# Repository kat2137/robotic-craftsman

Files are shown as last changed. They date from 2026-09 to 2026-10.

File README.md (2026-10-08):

# The Robotic Craftsman (Hania)

<p>
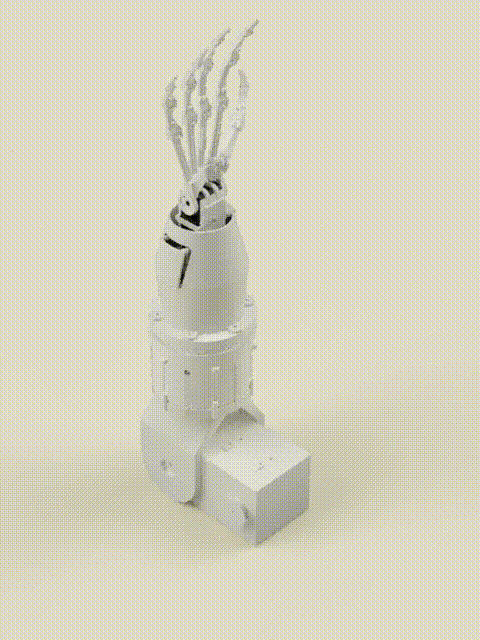
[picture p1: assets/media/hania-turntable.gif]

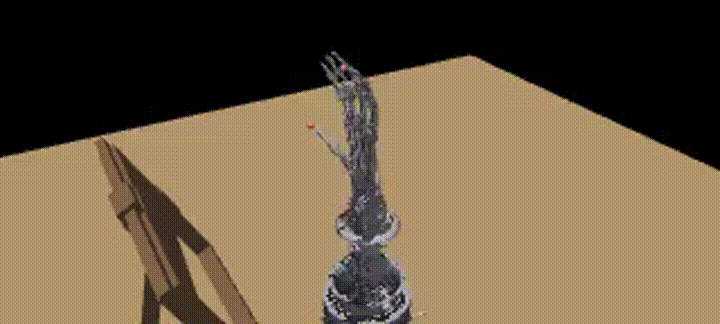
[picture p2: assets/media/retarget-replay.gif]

</p>

A robotic arm and tendon-driven hand built to reproduce hand-sewing on flimsy fabric. I filmed hand-sewing demonstrations, extracted 3D hand pose with WiLoR, and retargeted it onto my robot in MuJoCo, then onto the real arm. Arm, hand, electronics and code are my own design.

Project page: https://kat2137.github.io/dlugosz-site/

## Challenge fit
- **Own data.** All footage was collected by me: I filmed myself and other sewers on a Canon camera on a small tripod (fixed viewpoint, right hand sewing through fabric). The sample clip used below is `handsewing_01`.
- **Challenging embodiment.** Human hand → 3-DoF servo arm with a five-finger, tendon-driven hand. Task: holding and pushing a needle through deformable fabric.
- **Sim.** Retargeted trajectories replayed in MuJoCo on the robot's own model (`model/palm_with_frame.xml`, meshes exported from my Fusion 360 CAD), including a free-floating needle held between the pads.

<p>
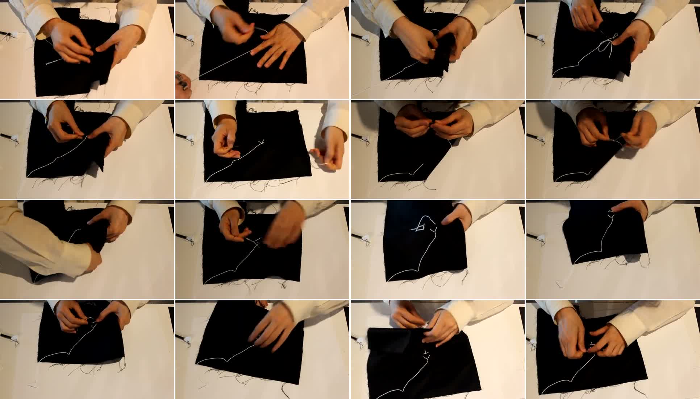
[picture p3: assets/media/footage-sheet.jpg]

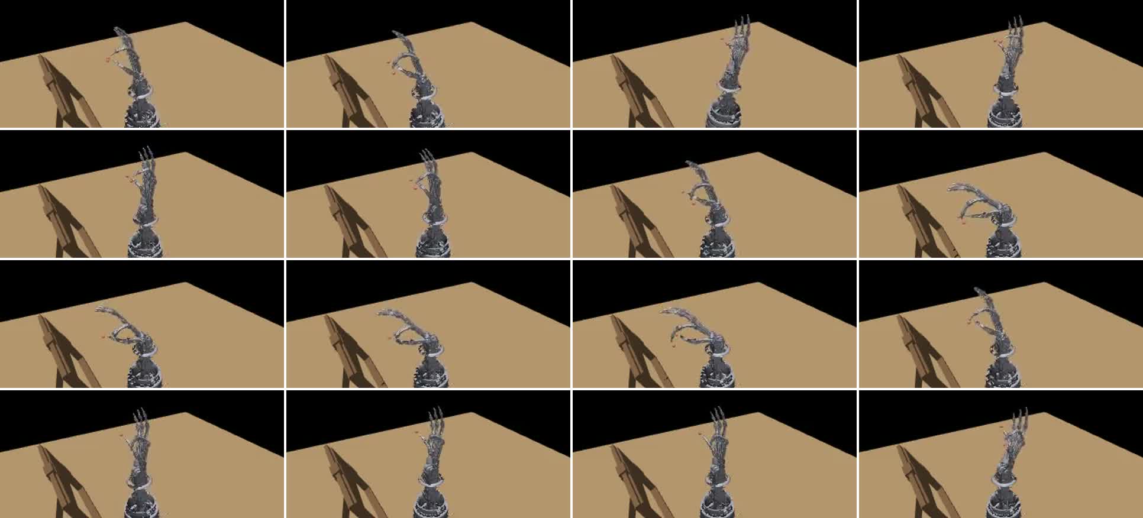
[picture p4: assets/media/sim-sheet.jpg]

</p>
<sub>Left: own footage, one frame every 5 s. Right: the same clip retargeted in MuJoCo.</sub>

## Pipeline
footage → WiLoR (21 keypoints/frame + camera translation) → hand-size scaling → fingertip retargeting (scipy L-BFGS-B) + elbow/wrist from palm frame → MuJoCo replay → real arm

<p>
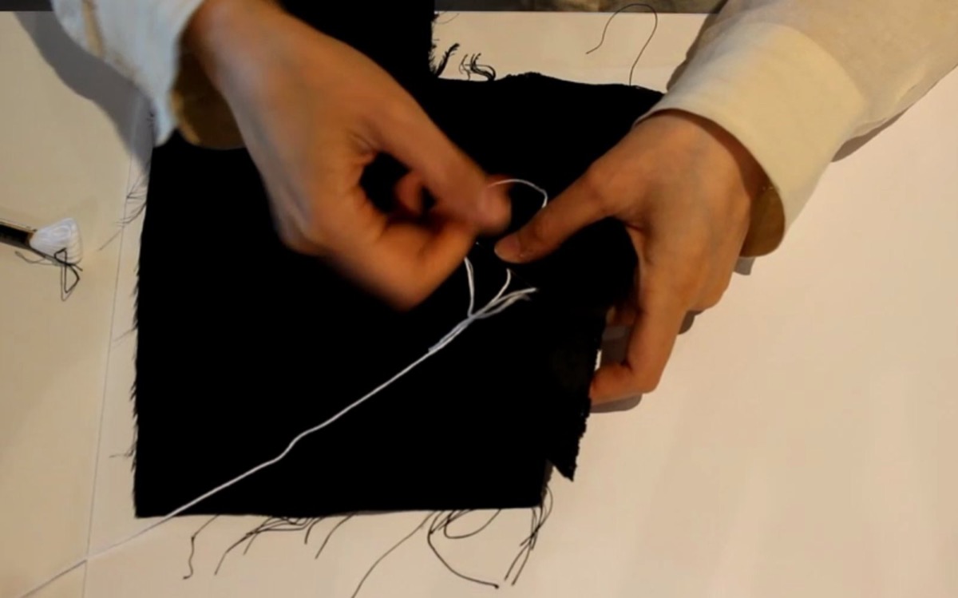
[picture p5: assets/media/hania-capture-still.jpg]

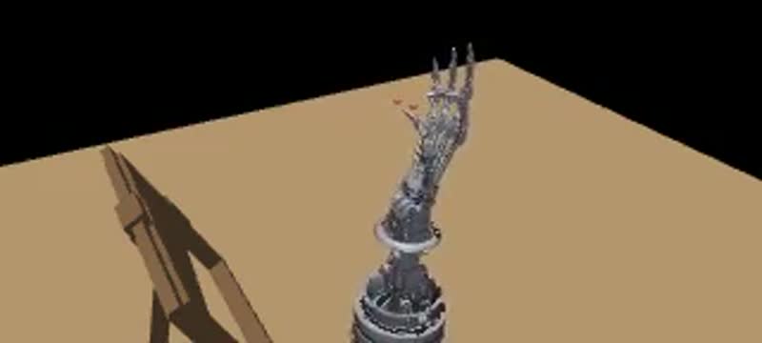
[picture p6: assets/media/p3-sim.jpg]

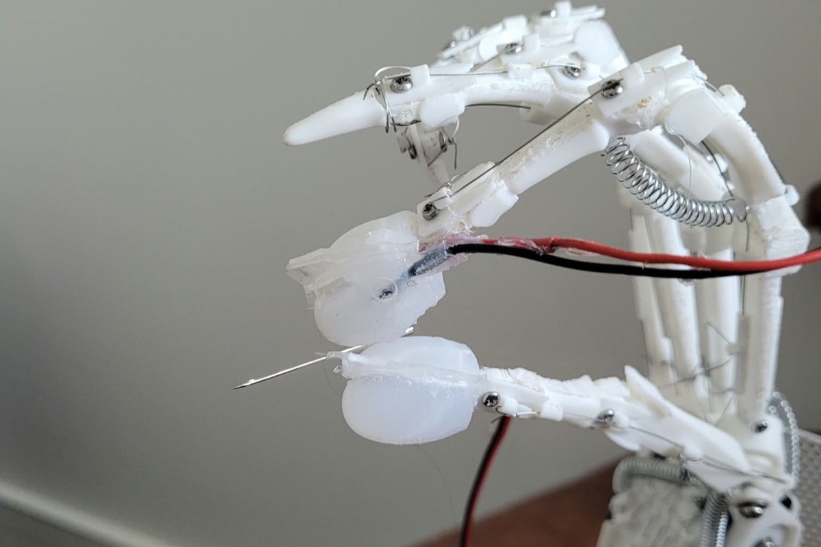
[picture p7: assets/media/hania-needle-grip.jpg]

</p>
<sub>Own footage → retargeted in MuJoCo → real hand holding a needle</sub>

- **Scaling.** Human-to-robot finger scale is measured once from the clip (`retargeting/wlr_hand_to_robot.py` → `main_motion/scale_retarget.json`).
- **Fingers.** Per frame, thumb and index joint angles are optimised so the robot fingertips reach the scaled human fingertip targets, within joint limits (`retargeting/retargeting_sim.py`).
- **Elbow.** Follows the wrist's travel from WiLoR camera translation.
- **Wrist roll/tilt.** Taken from the palm frame (index MCP, pinky MCP, middle MCP, wrist), not full position IK, which was unstable on noisy WiLoR wrist estimates.
- **Kinematics.** Forward kinematics built from the CAD joint frames with Rodrigues' rotation formula (`main_motion/f_kinematics.py`); law-of-cosines IK for the serial arm (`main_motion/i_kinematics.py`). Based on Jazar, *Theory of Applied Robotics*.

<p>
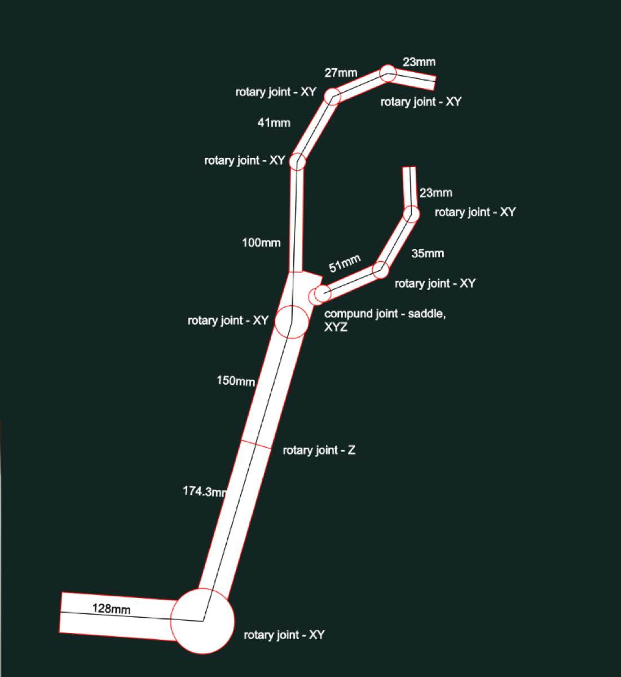
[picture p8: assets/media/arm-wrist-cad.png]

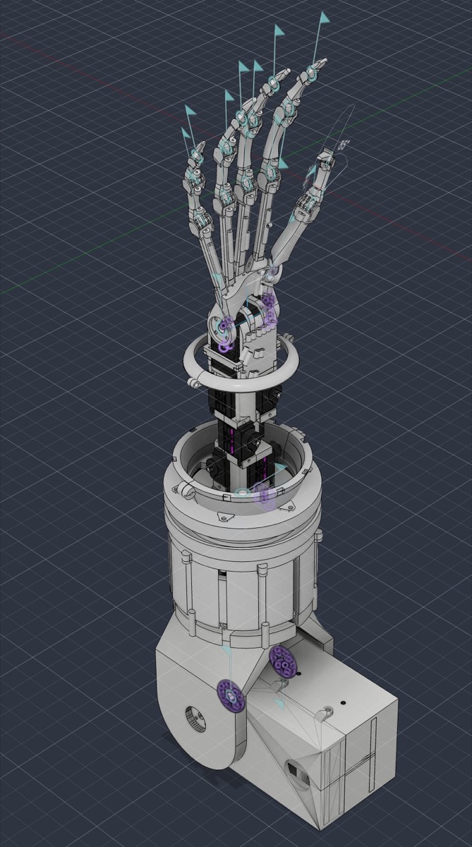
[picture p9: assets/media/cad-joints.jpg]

</p>
<sub>Kinematic chain with link lengths and joint types · joint frames in CAD</sub>

## Results
<p>
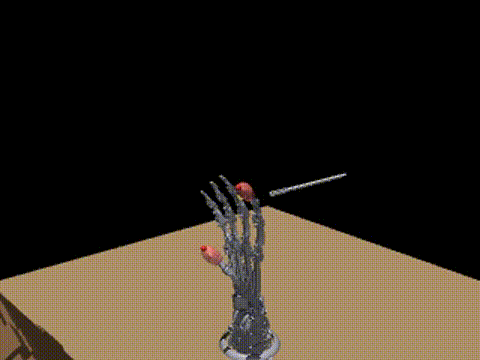
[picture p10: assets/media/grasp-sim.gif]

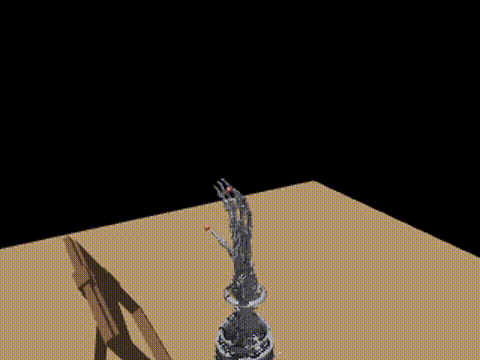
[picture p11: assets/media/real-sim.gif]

</p>
<sub>Left: needle grip in sim (`grip_sim.py`). Right: retargeted sewing motion (`retargeting_sim.py`).</sub>

- Fingertip retargeting residual over N frames: mean X, median Y (`assets/media/retarget_cost.png`)
- Real arm: thumb–index pinch holds the needle and the pinch switch detects it.

## Quickstart
Run from the repo root (scripts import `arm.py` from there):
```bash
python3 -m venv .venv && source .venv/bin/activate
pip install -r requirements.txt
python -m main_motion.mjc_demo              # model sanity check → out.mp4
python -m retargeting.wlr_hand_to_robot     # hand-size scales → main_motion/scale_retarget.json
python -m retargeting.retargeting_sim       # solve + render → solved_angles_new.npz, real_sim6.mp4
python -m retargeting.grip_sim              # needle grip in sim → grasp_sim.mp4
```
`retargeting/retargeting.py` is the same pipeline driving the real servos (Jetson, Linux).

WiLoR is not bundled (MANO licence). To process new footage: install WiLoR, run `visualize_pose_videos.py`, then `glob_json.py` to build the `[frames, 21, 3]` keypoint array.

## Design choices
- **Fingertip targets over per-joint angle copying.** Copying human joint angles ignores the robot's different link lengths, so the pinch didn't close. Solving for fingertip positions preserves the pinch, which is what holds the needle.
- **Palm-frame wrist over full IK.** WiLoR's wrist position is estimated relative to the fingers and is noisy; full position IK jittered.
- **Five-finger hand, two-finger task.** The needle grip is a thumb–index pinch, so only thumb (flexion + adduction) and index are retargeted.
- **Pinch switch for needle detection.** A conductive-thread pad is stitched through each silicone fingertip cap, with the thumb and index pads facing each other and each wired to the Jetson. A held needle bridges the pads.
- **One tendon per finger, spring return.** Each finger is flexed by a single Dyneema tendon through printed guides; extension springs open it again, so each finger needs one actuator.

<p>
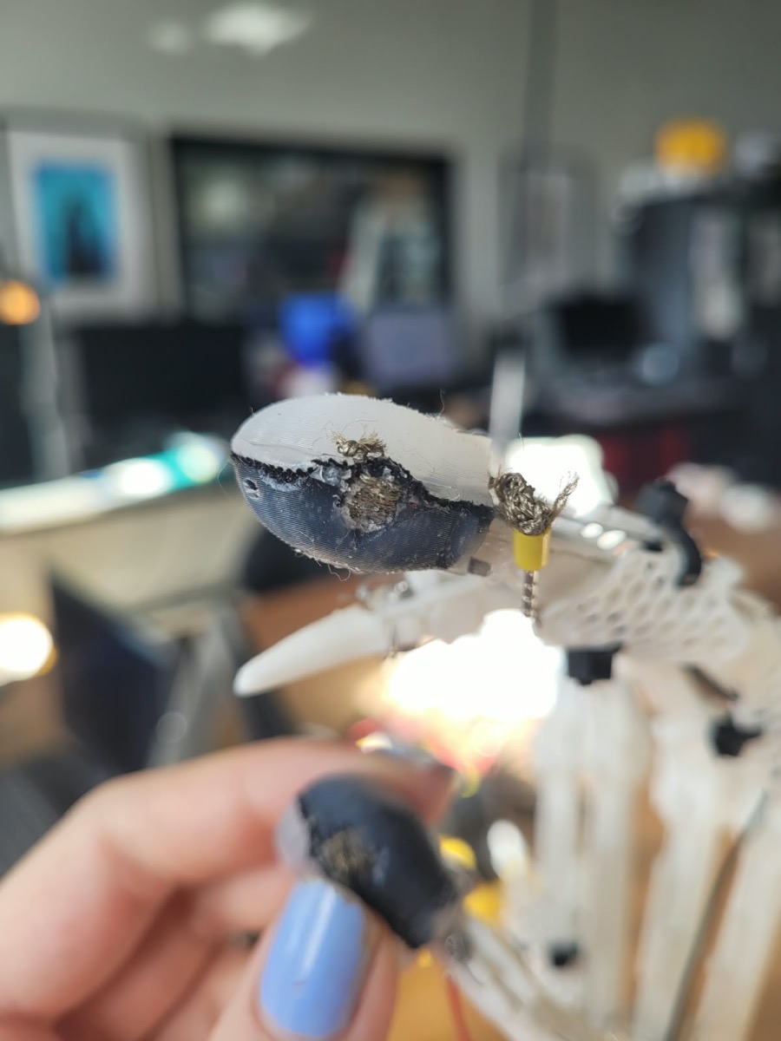
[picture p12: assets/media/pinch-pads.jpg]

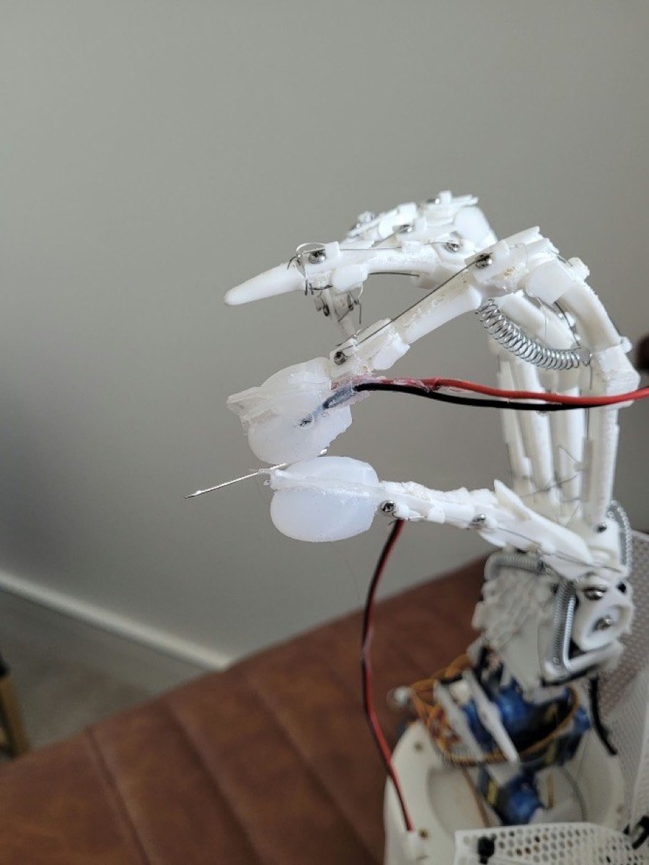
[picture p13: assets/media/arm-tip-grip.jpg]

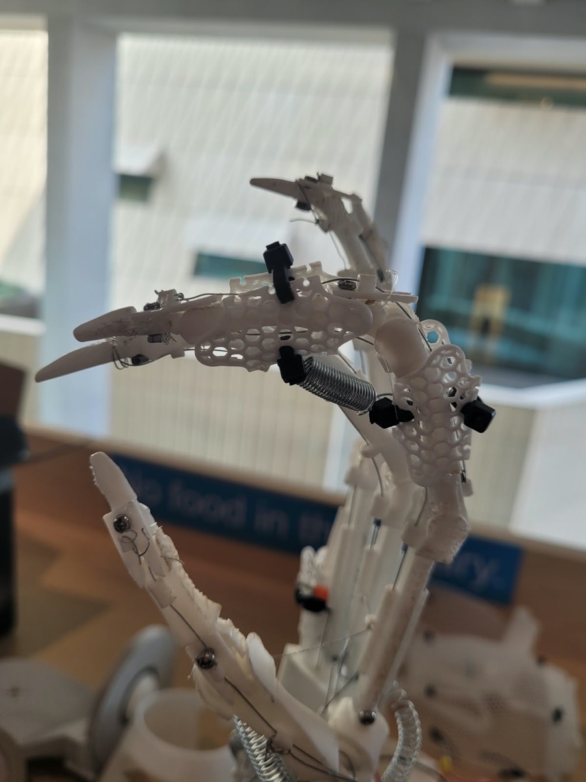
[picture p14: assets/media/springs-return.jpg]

</p>
<sub>Conductive-thread pad in the silicone cap · needle held between the pads · spring return and tendon guides</sub>

## What didn't work
- **Per-joint angle mapping:** see above and `notes.md`.
- **IR sensing (ITR-9606) through the silicone caps:** signal too weak through the silicone (`itr_test.py`); replaced by the pinch switch.
- **Arm base lying on its side, as in the CAD:** sagged under load; the real base now stands on its face.
- **Dyneema creep:** tendons stretched over time, requiring re-tensioning and recalibration (`finger_calib.json`).

## Limitations and next steps
- No learned policy yet: the robot replays retargeted demonstrations.
- Next: imitation learning on the hand-sewing demonstrations, RL fine-tuning in sim, then Isaac Lab for sim-to-real.

## Hardware
- Jetson Orin Nano
- 3× ST3215 bus servos: wrist roll (ID 1), wrist tilt (ID 2), elbow (ID 3, 2:1 gearing)
- PWM finger servos on a PCA9685 driver, one tendon each
- Silicone fingertip caps with conductive-thread pads
- 3D-printed arm and hand (STLs in `model/meshes/`)

<p>
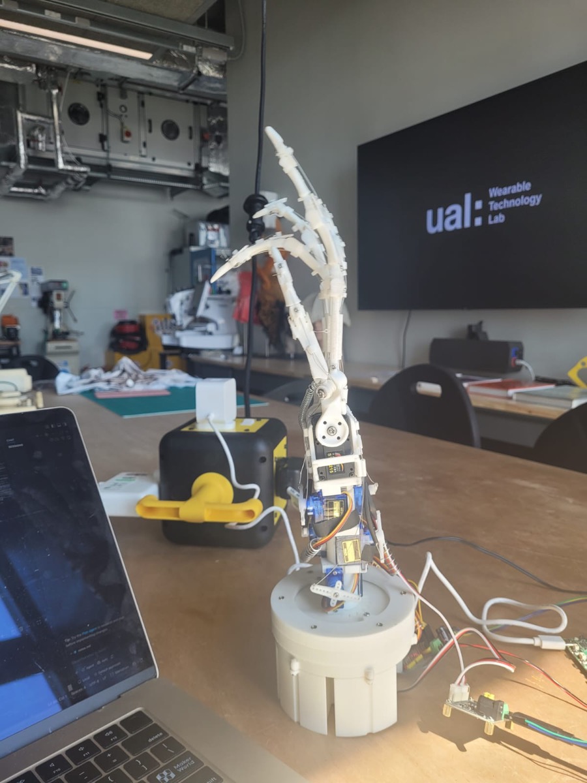
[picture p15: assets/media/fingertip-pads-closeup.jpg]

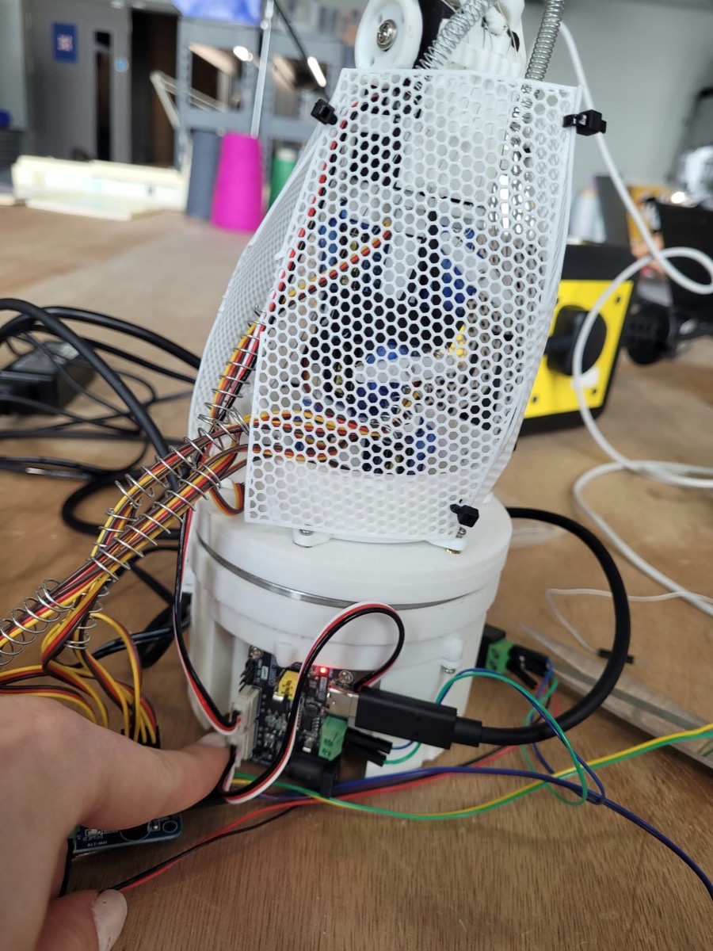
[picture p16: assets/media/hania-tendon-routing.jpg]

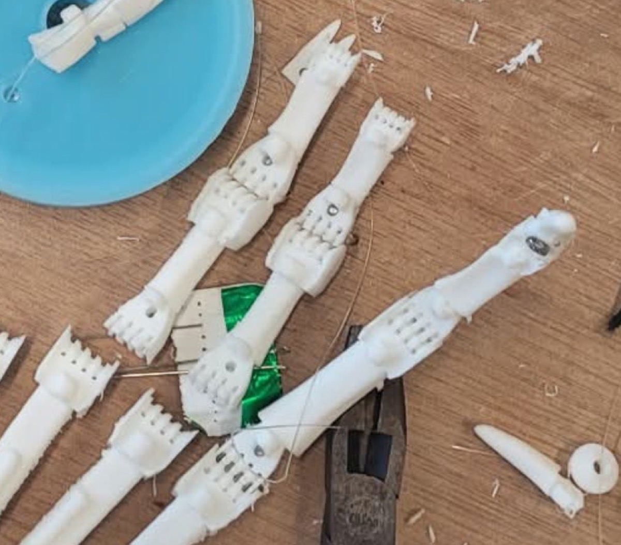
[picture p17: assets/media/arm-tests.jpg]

</p>
<sub>Assembled arm · electronics in the forearm · printed finger parts</sub>

## Repo map
| Path | Contents |
|---|---|
| `arm.py` | Core classes: ST and PWM servos, calibration, hand pose, MuJoCo wrapper, camera |
| `retargeting/` | Hand-size scaling, retargeting (sim and real), needle-grip sim |
| `main_motion/` | Forward/inverse kinematics, MuJoCo demo and joint map, grasp tests |
| `main_motion/calib/` | Joint limits, angle mapping, position logging against video |
| `model/` | MuJoCo MJCF and STL meshes |
| `cam/` | CSI camera setup, checkerboard calibration, object/needle estimation |
| `scservo_sdk/` | Vendored Feetech SDK for the ST3215 servos |
| `visualize_pose*.py`, `glob_json.py`, `angle_computation.py` | WiLoR processing and angle extraction |
| `finger_calib.json` | Finger calibration from grasp tests |
| `notes.md` | Development log |
| `retired/` | Superseded approaches, including early servo setup scripts |

## Credits
WiLoR (hand pose). Jazar, *Theory of Applied Robotics*. AI was used for explanations and as a diagnostic tool when I was stuck; all code was written by me (see `notes.md`).

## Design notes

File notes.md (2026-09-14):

STAGE 1

Using WiLoR on Macbook CPU takes a lot of time and processing is lenghty.
I used source code from WiLoR demo.py to change the pipeline for video format - visualize_pose_videos.py and added a plotting layer - visualize_pose.py

WiLoR output per frame should be read in this manner:

Wrist - index 0 
Thumb - indices (joint numbers) 1-4;
Fingertip - 4

Index - indices (joint numbers) 5-8;
Fingertip - 8

Middle - indices (joint numbers) 9-12;
Fingertip - 12

Ring - indices (joint numbers) 13-16;
Fingertip - 16

Pinky - indices (joint numbers) 17-20;
Fingertip - 20

To position the wrist location in space, camera_translation needs to be applied to the hand position

STAGE 2 
After adjusting the output format to only joints position (vertices deleted) and confidence score - relevant for robotic translation, the JSON output should be analysed (broken down into singular important phases of the captured activity). My notes about the frame analysis where:
Frame 000000- 000030 - positioning the needle in between the fingertips 

Frame 000030- 00058 - pushing the needle through one layer of fabric with right hand - left hand holds the fabric. Needle position changes to vertical to stab through the fabric layer

 Re-directing the needle end to re-pierce the fabric. Starting position - Needle still held by the fingers from top fabric layer (20% of the needle outside, 80% of the needle is through\on the other side of the fabric).Hand turns the needle holding that 20% to pierce the fabric and extract the needle from its tip. The middle and the ring finger help redirect the needle (move it from vertical to horizontal in relation to the fabric or table position)

Frame 000059 - 000069 FLAG - the hand releases the needle end and travels to grab the pointy end
Frame 000070 - hand attempts to grab the pointy end
Frame 000071 - 000100 needle is pulled outwards, to pull the thread through a previously marked track

Frames 000100 - 000195
Ignore - user reaches for thread, irrelevant to the gesture

Frames 000195 - 000211
The needle is repositioned against the fabric layer at a steep angle to pierce through

Frames 000212 - 000223
The needle is inserted into fabric and pushed horizontally. Fabric is manipulated by the left hand to conform to the needle

Frames 000224 - 000320

Needle is being pushed through the fabric to stick out on the other side, while the tip is being held. The hand turns the needle to a vertical, and then a horizontal position again - to pierce it through the fabric in a direction opposite to the previous. Force is applied to insert the needle in between two holes - insertion point and extraction point.

Frames 000321 - 000330 FLAG - needle is released. The hand travels to the pointy end to extract it

Frame 000331 - 000332the hand arrived at the extraction point, it grasps the tip.

Frame 000333 - 000339
The needle is being pulled by the tip to be extracted from under the fabric. The other hand hold the fabric down to accelerate the step.

After understanding the division and form of the output, the JSON files are globbed using glob_json.py to produce a three-dimensional NumPy array in this format: npz = [n_frames, 21, 3], in which npz[0] tells you which frame it is, npz[1] which one of the 21 joints coordinates you're looking at, and npz[2] lists the x,y,z coordinates for the respective joint. I didn't come up with that method of analysis on my own, I inserted the WiLoR repo + my analysis into Claude to understand how to do it. All the code edits were done by myself, as I only relied on AI for gaining process knowledge.

WiLoR analysis is not very good for estimating wrist position - the wrist position is portrayed in relation to the finger joints, which means it doesn't indicate bend or rotation.

WiLoR also sometimes flips the left hand on the drawing. That was fixed in glob_json but during globbing, I remembered that for the first demo i just need the right hand tracking - so I removed that part until later. I will probably add another globbing file to get the readible output of both hands for the future development. 

Retargeting to servos uses simple kinematics in relation to local frame P = wrist for mcp flexion angle and P = mcp for pip and tip flexion, treating each segment as a vector with start and end coordinates at each joint, f.e. for thumb tip-to-pip segment, vector t, coordinates in the index 4 from the json frame is the start of the vector, and index 3 is the end. 
The angle in between vectors a and b is derived from dot product of a and b divided by the dot product of their lenght.

The tendon architecture of the robot is designed with singe tendon per finger but the script can be easily modified to include double tendon architecture.

Specific notes for servos in my wiring setup - irrelevant if you're wiring them yourself:
Channel 0 - finger 1 - thumb adduction | max backwards motion - 2200us | max adduction - 800us |
Channel 1 - finger 1 - thumb  | max straightening - 2000 us| max flex - 800us |
Channel 2 - finger 3 - middle | max straightening - 1500us | max flex - 2400us |
Channel 3 - finger 4 - ring   | max straightening - 1600us | max flex - 500us |
Channel 4 - finger 5 - pinkie | max straightening - 1700us | max flex - 1000us |
Channel 5 - finger 2 - index  | max straightening - 2400us | max flex - 1300us |

STAGE 2 - Wrist setup

Demo's own comments: speed × 0.732 = rpm, and acceleration × 8.7 = deg/s².

Wrist tilt - ID 2 | max straightening - 3000 | max flex - 2200 |
wrist rotation - ID 1 | range from 2000 - 4095 |
acceleration
speed

What needs to be added is a tendon displacement leeway for wrist tilt. It's a natural occurence in human anatomy, called tendosis. Because finger tendons are attached to bones below the wrist, tilting the wrist stretched/relaxes the tendons. I recommend reading more on that on Wikipedia.

To acknlowledge the difference that needs to be applied to the finger position if the wrist moves, an equation ...
k = ?

Grasping setting on no wrist tilt (3000) =  ch 0 = 1800us, ch 1 = 1000us and ch 5 = 1600/1550us

# I should write more about wrist and rotation servos and the camera, but it was difficult so i will add that later

To write forward and inverse kinematics, which calculates the automatic position of every joint based on the needed position of the end-effector. The end-effector in my case is the gripper, which are the index and thumb fingertips. All the equations are based on Theory of applied robotics : kinematics, dynamics, and control / Jazar, Reza N. and turned into python by looking everything up online.
It took me a only few days to understand kinematics and matrix transformations, which means they are not too complicated even if you're not a Maths major. All of them are in #f_kinematics.py and #i_kinematics.py

I conducted some manual grasping tests with silicon-cured fingertips, which were captured in grasping_tests.py and grasp_test2.py. Based on that, I produced a finger_calib.json doc describing positions of grasping for the robot.

main_motion/calib is where calibration against the real design sits. Limits.py includes observed limits for each joint that later will be used as a range limit for kinematics operations. 
Calibration was aimed at figuring what's the bending ratio in between the phalanges of the fingers, and for that, I wanted to plot the Wilor xyz points on the frames and compare the angle output with the real output about servo activity.
I filmed a video, located in calib/data, meanwhile using position_log.py, I triggered and recorded all motion ranges of all links. I labelled each in vid_log.csv and matched it to position_log in timelapse_helper_script.py. It was mostly for me to also learn about data structures and pandas' df, it could have been matched just by eliminating the time delay from the log but I tried different methods to learn these operations.

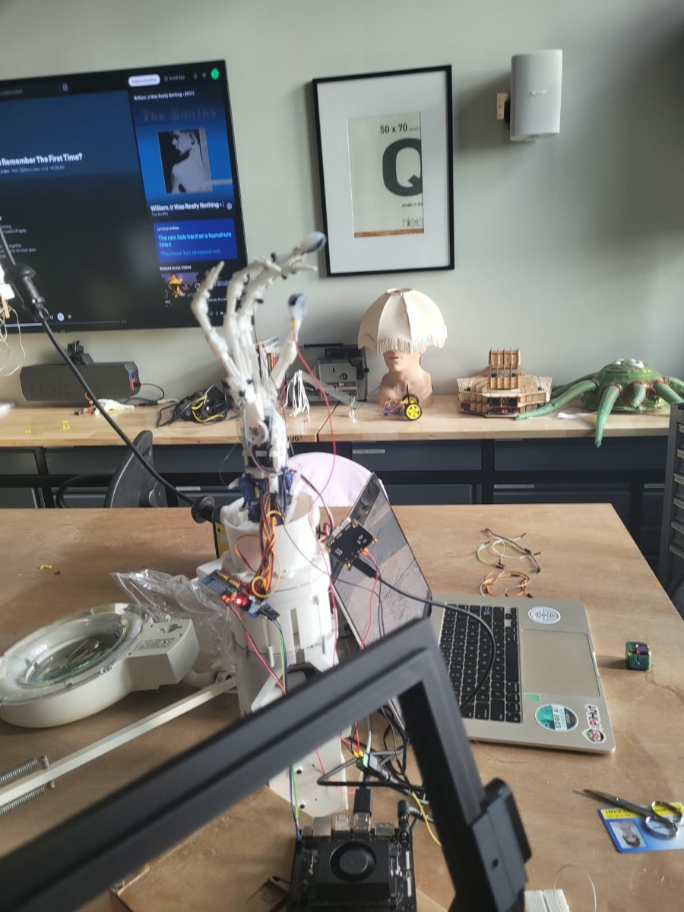
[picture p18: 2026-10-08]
assets/media/hania-bench.jpg

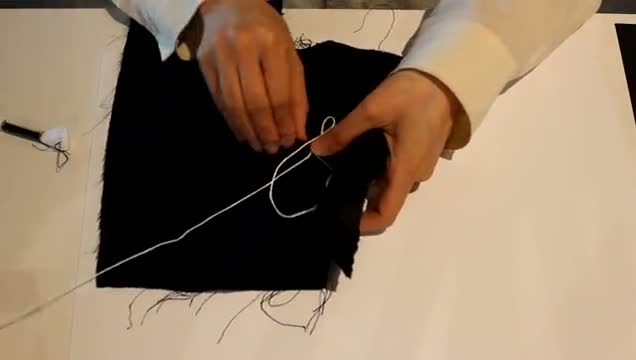
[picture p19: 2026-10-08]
assets/media/p1-footage.jpg

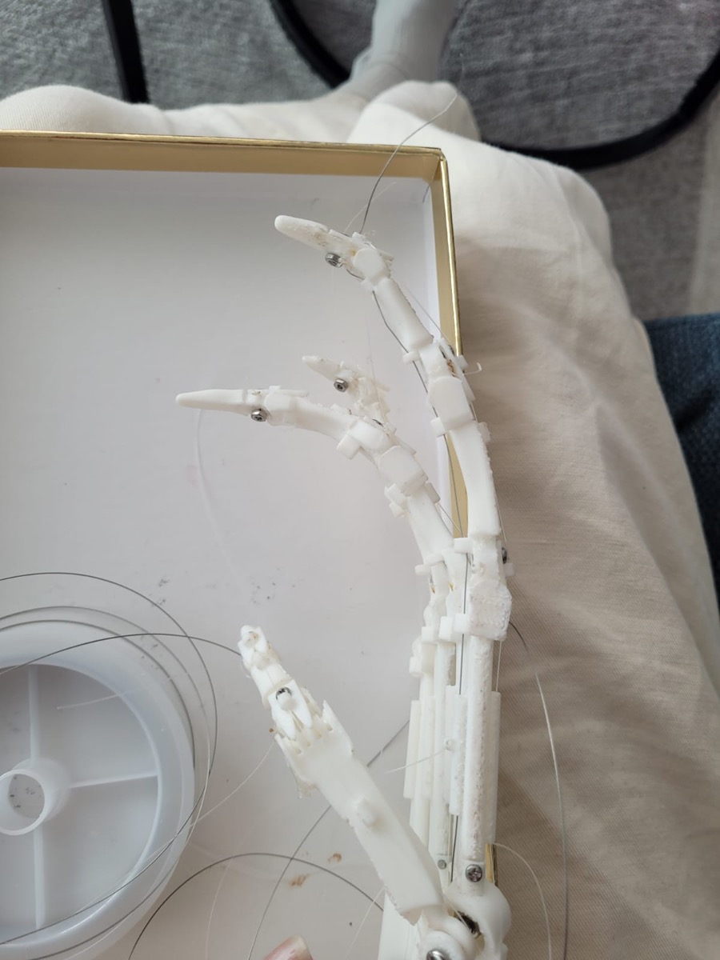
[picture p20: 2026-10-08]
assets/media/hand-springs-tendons.jpg

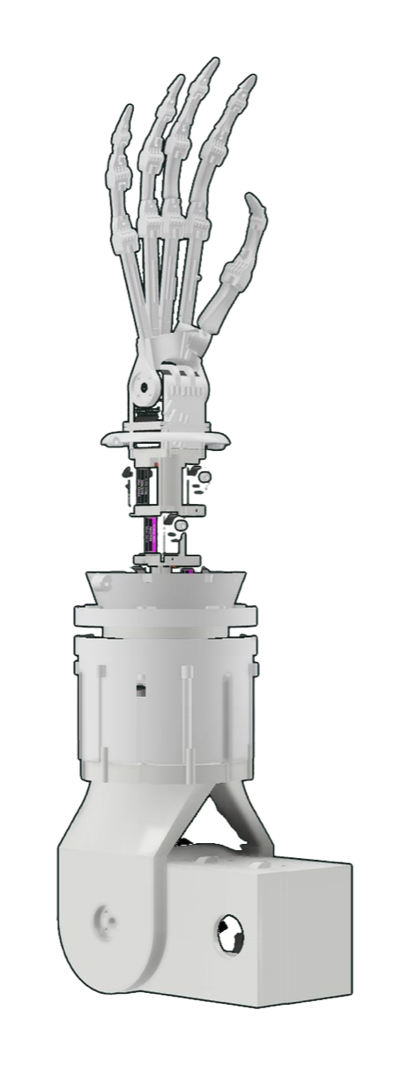
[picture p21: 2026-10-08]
assets/media/hania-cutout.png

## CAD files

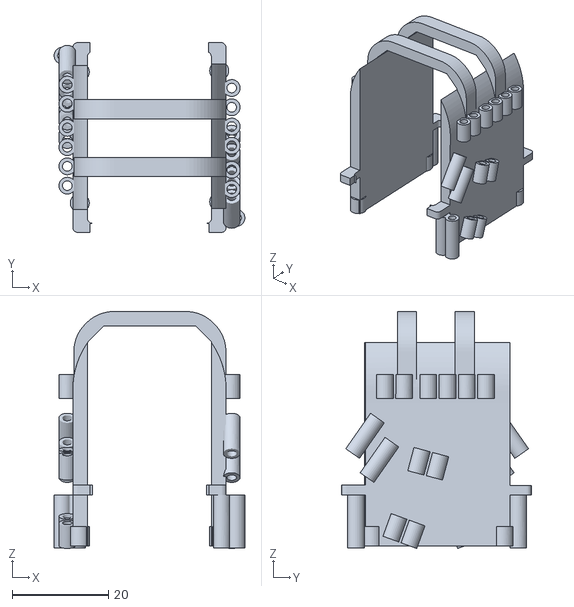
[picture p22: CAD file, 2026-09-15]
model/meshes/wristframe_main.stl
39.6 x 39.4 x 49.2

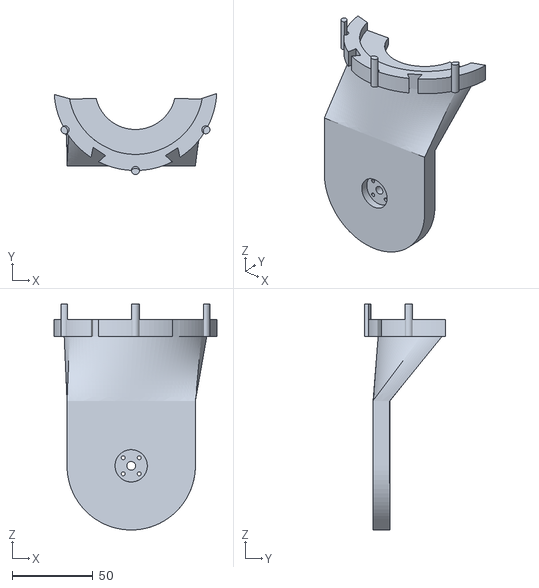
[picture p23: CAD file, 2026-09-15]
model/meshes/elbow_main2.stl
100.6 x 50.1 x 139.9

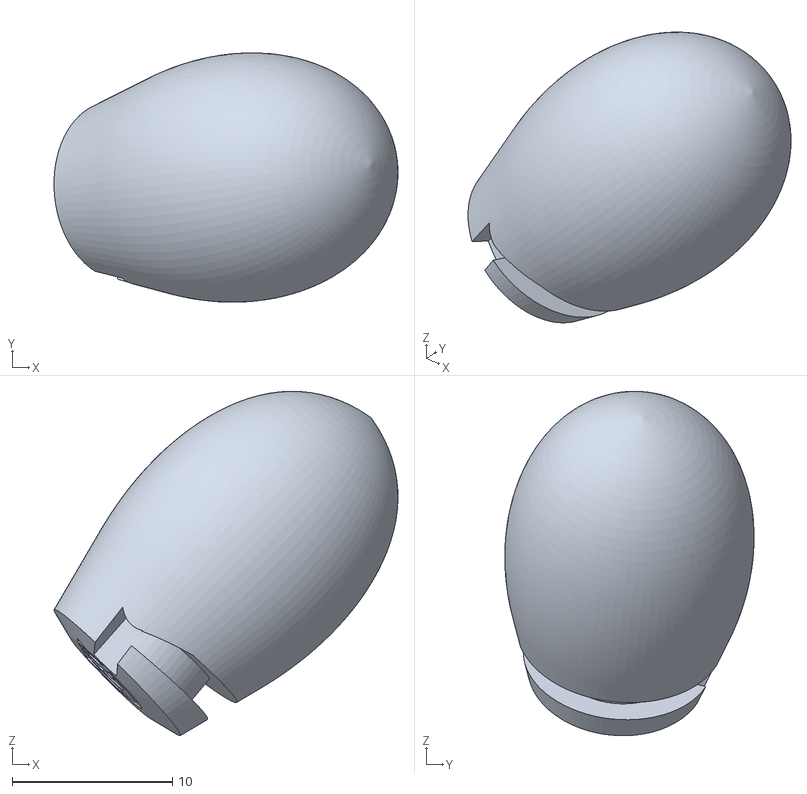
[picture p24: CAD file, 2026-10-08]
model/meshes/finger_pad.stl
21.5 x 15.6 x 21.5

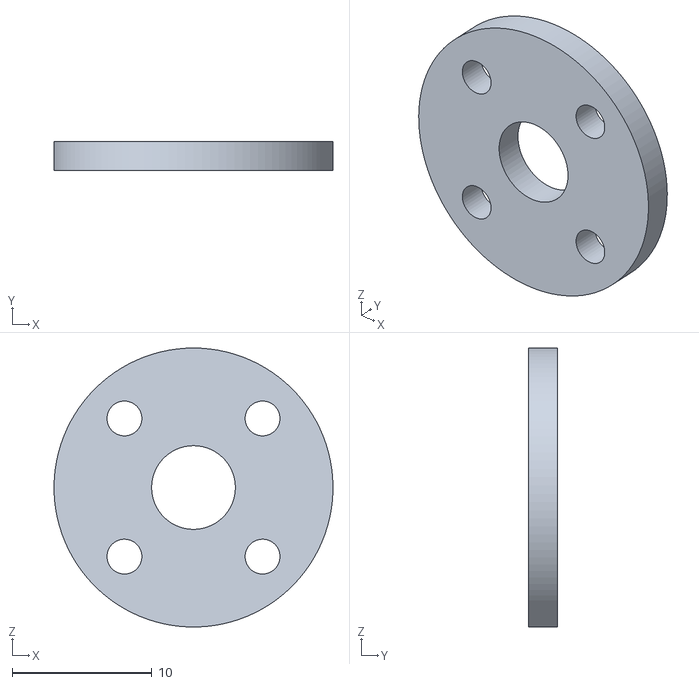
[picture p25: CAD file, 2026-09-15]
model/meshes/wrist_servo_plat1.stl
20.0 x 2.10 x 20.0

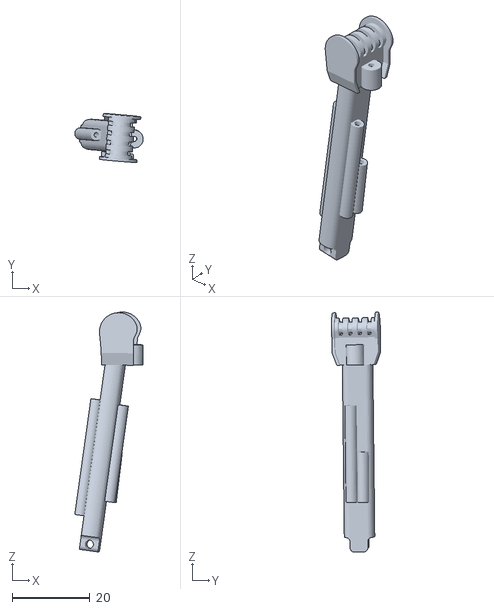
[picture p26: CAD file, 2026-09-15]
model/meshes/mid_mcp.stl
17.6 x 12.6 x 61.6

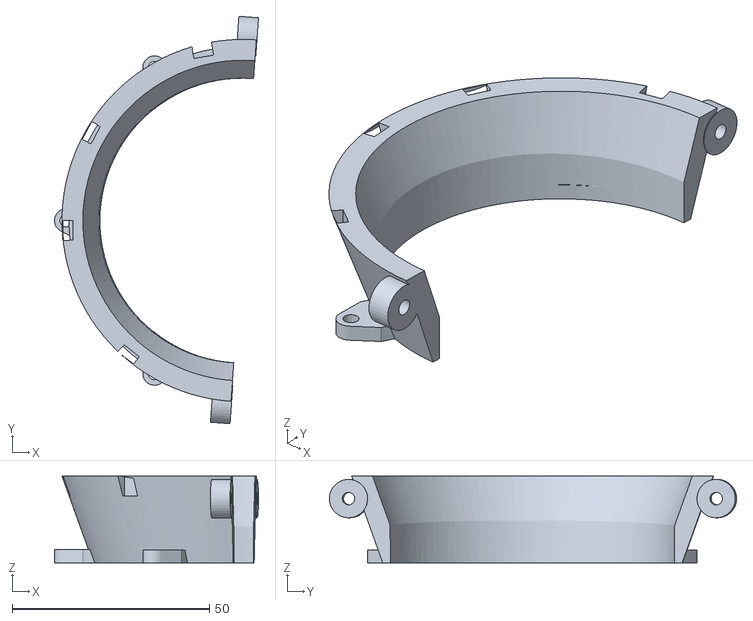
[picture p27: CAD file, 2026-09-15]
model/meshes/midarm_frame2.stl
51.8 x 103.3 x 22.0

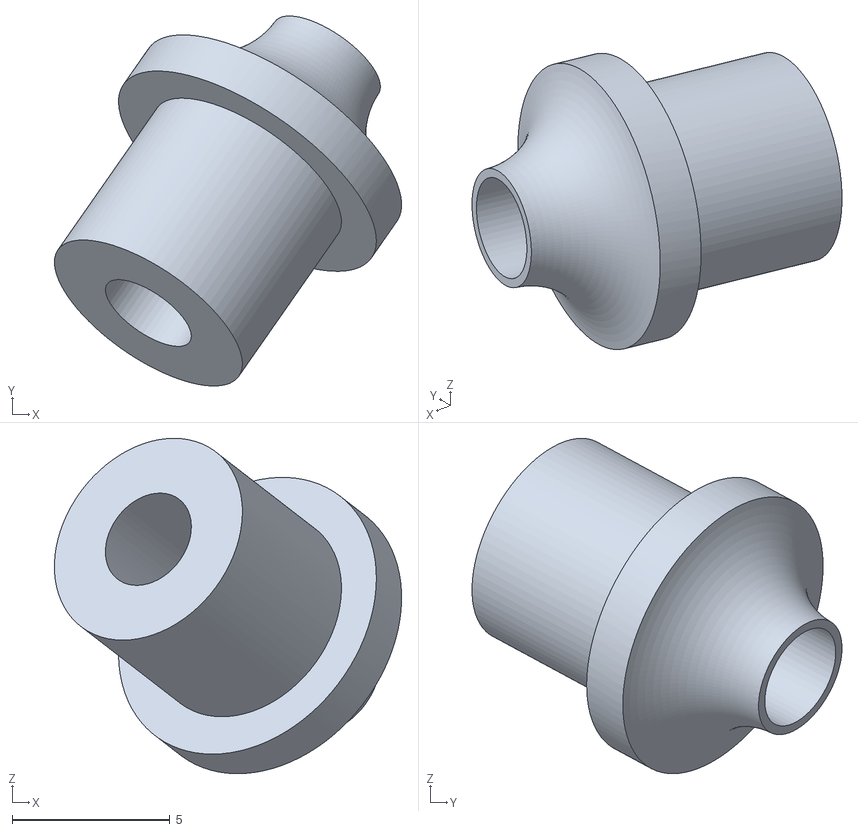
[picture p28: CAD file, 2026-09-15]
model/meshes/saddle_2-1.stl
11.0 x 11.7 x 10.6

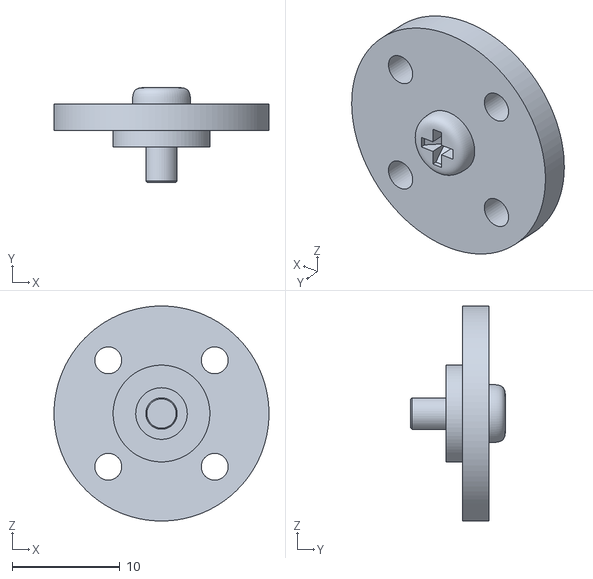
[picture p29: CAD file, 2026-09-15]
model/meshes/wrist_servo_plat2.stl
20.0 x 8.80 x 20.0

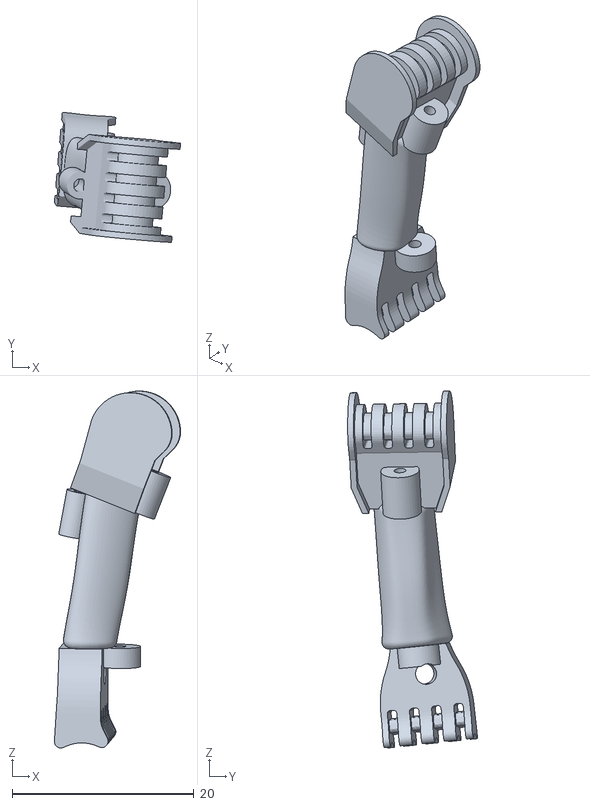
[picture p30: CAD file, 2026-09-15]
model/meshes/ring_pip.stl
13.9 x 14.3 x 39.2

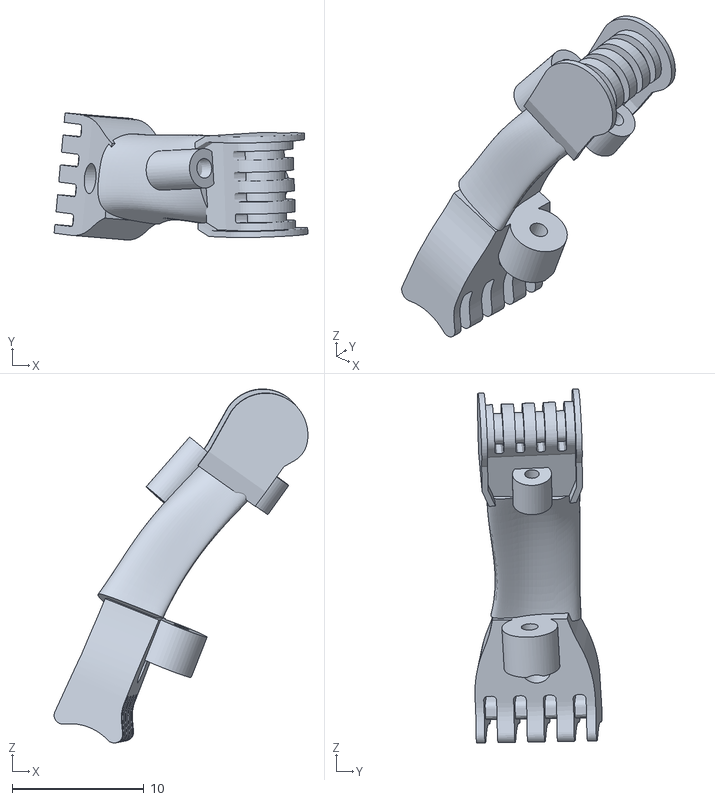
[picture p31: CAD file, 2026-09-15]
model/meshes/ring_mip.stl
19.3 x 9.66 x 26.9

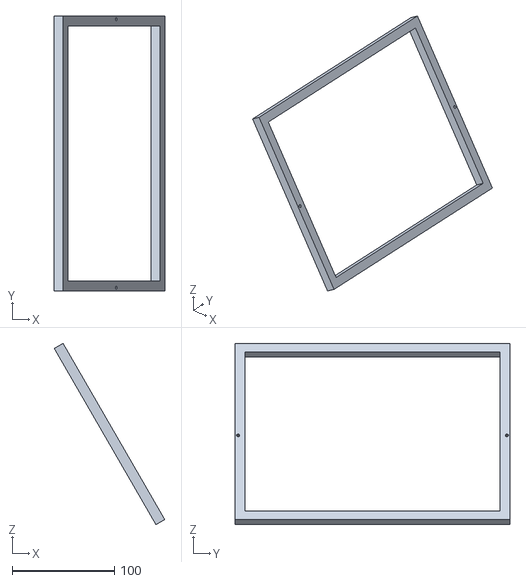
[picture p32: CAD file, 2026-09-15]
model/meshes/inside_frame.stl
108.3 x 269.3 x 177.5

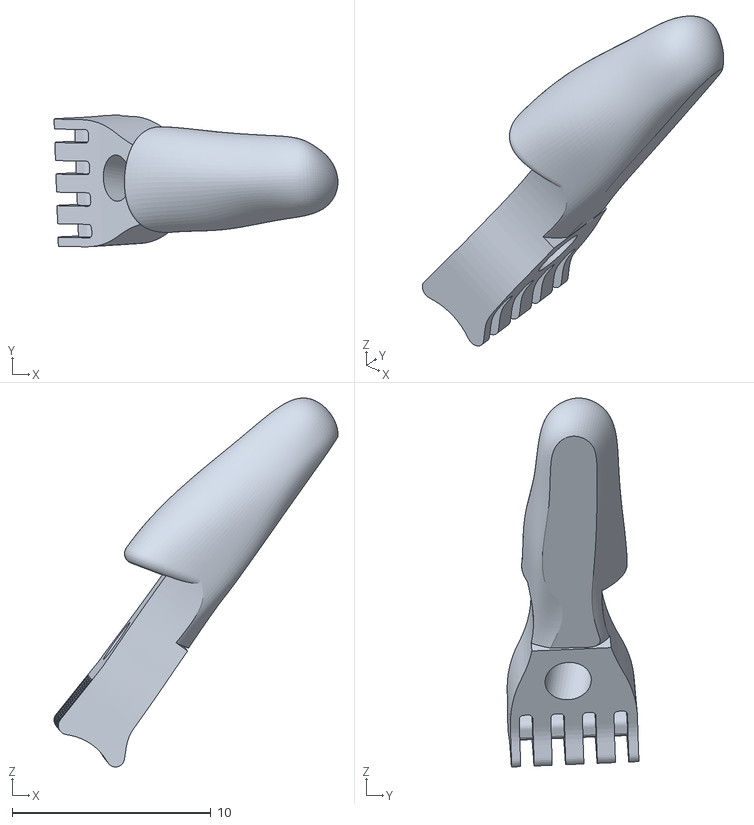
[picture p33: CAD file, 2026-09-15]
model/meshes/ring_tip.stl
14.3 x 6.63 x 18.6

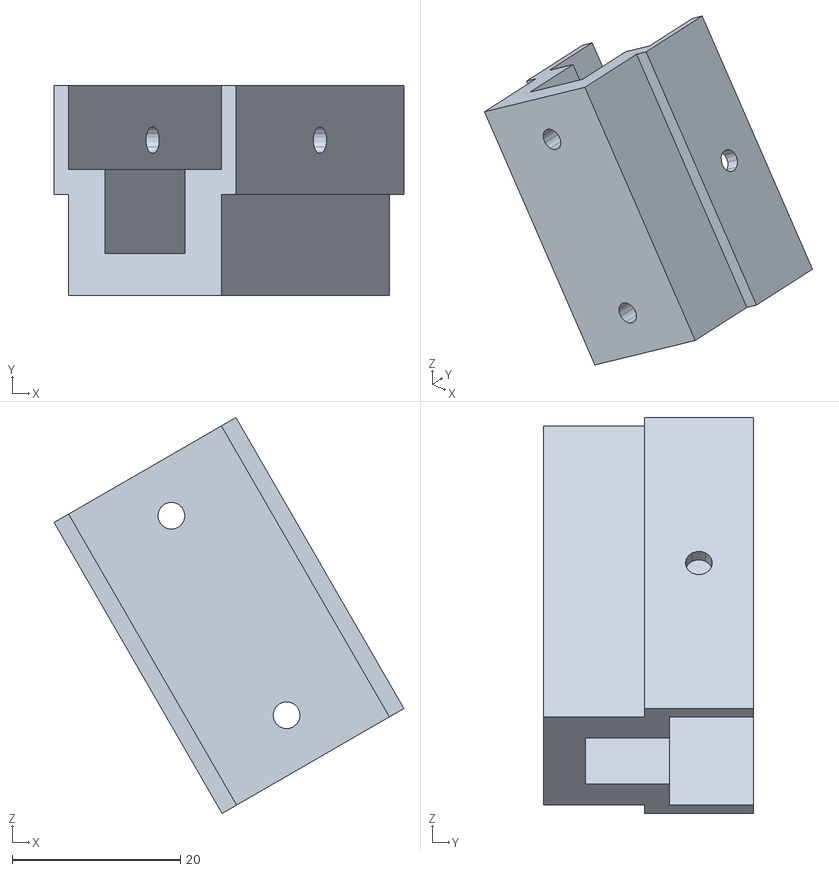
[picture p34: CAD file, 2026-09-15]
model/meshes/frame_clipper2.stl
41.7 x 25.0 x 47.1

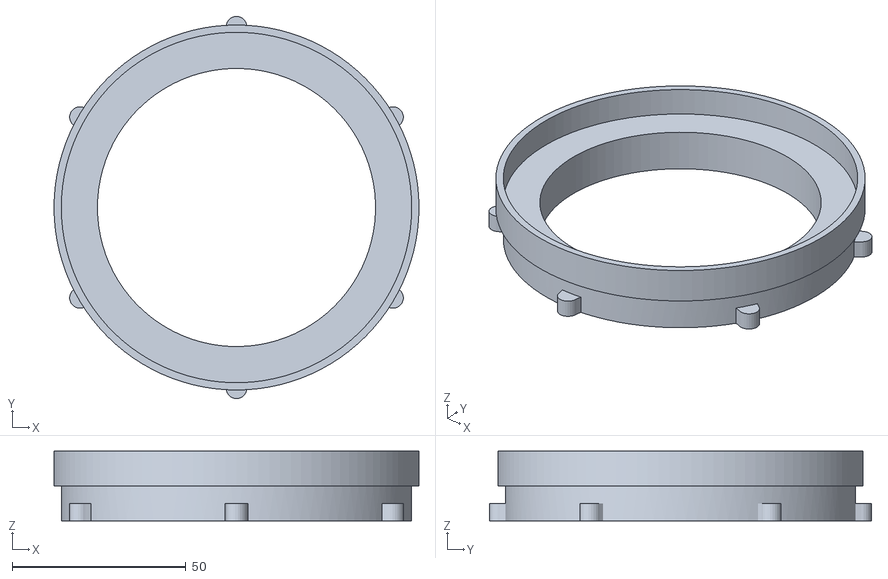
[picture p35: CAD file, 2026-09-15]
model/meshes/bottom_rotation-wheel.stl
105.0 x 109.9 x 20.0

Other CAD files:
model/meshes/elbow_main1.stl
model/meshes/small_tip.stl
model/meshes/inside_rotation-cog.stl
model/meshes/outer_frame-1.stl
model/meshes/2076278-v1.stl
model/meshes/Craft_Needle.STL
model/meshes/arm1-1.stl
model/meshes/arm2-1.stl
model/meshes/base-1.stl
model/meshes/base1.stl
model/meshes/bearing_cap_midarm.stl
model/meshes/case_midarm.stl
model/meshes/case_midarm2.stl
model/meshes/elbow_case2-v1.stl
model/meshes/finger_servo1.stl
model/meshes/frame_clipper1.stl
model/meshes/index_mcp.stl
model/meshes/index_mip.stl
model/meshes/index_pip.stl
model/meshes/index_tip.stl
model/meshes/inside_rotation_bearing_frame.stl
model/meshes/inside_rotation_wheel.stl
model/meshes/mid_mip.stl
model/meshes/mid_tip.stl
model/meshes/midarm1.stl
model/meshes/midarm_frame1.stl
model/meshes/midarm_frame3.stl
model/meshes/midarm_frame4.stl
model/meshes/middle_pip.stl
model/meshes/ring_mcp.stl
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

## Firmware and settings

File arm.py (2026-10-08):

"""Core classes for the robotic craftsman arm.

Every other module imports its hardware, calibration, kinematics, simulation and
camera helpers from here.

Nothing in this file touches hardware at import time. scservo_sdk, the PCA9685
libraries, board/busio, mujoco and cv2 are imported inside the methods that need
them, so `import arm` works on a Mac with nothing plugged in.

Channel naming (confirmed on video 10 Sept):
    ch0 = thumb adduction ("thumb_add")
    ch1 = thumb flexion   ("thumb")
    ch5 = index           ("index")
"""

import glob
import json
from dataclasses import dataclass, field
from pathlib import Path
from typing import Literal, Optional

import numpy as np

# --- paths -------------------------------------------------------------------

ROOT = Path(__file__).resolve().parent
FINGER_CALIB_PATH = ROOT / "finger_calib.json"
RATIOS_PATH = ROOT / "main_motion" / "ratios.json"
SCALES_PATH = ROOT / "main_motion" / "scale_retarget.json"
XML_PATH = ROOT / "model" / "palm_with_frame.xml"
NPZ_PATH = ROOT / "handsewing_01.npz"

# --- ST bus servos (wrist rotate, wrist tilt, elbow) ------------------------

ST_PORT_LINUX = "/dev/ttyACM0"
ST_BAUD = 1000000
ST_BROADCAST_ID = 0xFE        # 254 = broadcast
COUNTS_PER_DEG = 4096 / 360
GEAR_RATIO = {1:1.0, 2:1.0, 3:2.0}   # STS3215: 4096 counts per turn


ST_SERVOS = {
    "wrist rotate": {"id": 1, "pos": 2059, "straight": 2048, "flexed": 4095, "min": 2000, "max": 4095},
    "wrist tilt":   {"id": 2, "pos": 2043, "straight": 2048, "flexed": 4095, "min": 2200, "max": 3000},
    "elbow":        {"id": 3, "pos": 3052, "straight": 2048, "flexed": 4095, "min": None, "max": None},
}

# --- PCA9685 finger servos ---------------------------------------------------

PWM_FREQ = 60
US_MIN, US_MID, US_MAX = 1000, 1500, 2000
LEGACY_US_PER_COUNT = 4.07            # Adafruit_PCA9685 set_pwm path, 60 Hz
LEGACY_COUNT_MIN, LEGACY_COUNT_MAX = 100, 600

# Order of the six angle columns from HandPose.apply_angles_arr
FINGER_ORDER = ["thumb_add", "thumb", "middle", "ring", "pinkie", "index"]

# Channels not yet in finger_calib.json (it only holds the two pinching fingers).
EXTRA_FINGERS = {
    0: {"name": "thumb add","straight":2200, "flexed": 800},
    1: {"name": "thumb",  "straight": 2000,   "flexed": 800},
    2: {"name": "middle", "straight": 1500, "flexed": 2400},
    3: {"name": "ring",   "straight": 1600, "flexed": 500},
    4: {"name": "pinkie", "straight": 1700, "flexed": 1000},
    5: {"name": "index",  "straight":  2200, "flexed": 1300 }
}


# =============================================================================
# Calibration
# =============================================================================

@dataclass
class Calibration:
    """finger_calib.json + ratios.json (w_spring) + scale_retarget.json in one place.

    Joint limits in radians and the MJCF coupling ratios live in the MuJoCo model;
    read them with MjcArm.joint_range() / MjcArm.couplings().
    """
    finger_calib: dict
    ratios: dict
    scales: dict

    @classmethod
    def load(cls, finger_path=FINGER_CALIB_PATH, ratios_path=RATIOS_PATH, scales_path=SCALES_PATH):
        with open(finger_path) as f:
            finger_calib = json.load(f)
        with open(ratios_path) as f:
            ratios = json.load(f)
        with open(scales_path) as f:
            scales = json.load(f)
        return cls(finger_calib, ratios, scales)

    # finger_calib.json
    @property
    def channels(self) -> dict:
        """Raw channel table, keyed by channel string: "0" -> {name, position, ...}."""
        return self.finger_calib["channels"]

    @property
    def wrist_tilt_ref(self) -> int:
        return self.finger_calib["wrist_tilt_ref"]

    @property
    def wrist_id(self) -> int:
        return self.finger_calib.get("wrist_id", 2)

    @property
    def wrist_speed(self) -> int:
        return self.finger_calib.get("wrist_speed", 100)

    @property
    def wrist_accel(self) -> int:
        return self.finger_calib.get("wrist_accel", 100)

    @property
    def tenodesis_k(self) -> float:
        """P_f = T_f + k * (P_w - P_w0)"""
        return self.finger_calib.get("tenodesis_k", 0.02)

    @property
    def st_port(self) -> str:
        return self.finger_calib.get("st_port", ST_PORT_LINUX)

    @property
    def st_baud(self) -> int:
        return self.finger_calib.get("st_baud", ST_BAUD)

    @property
    def pwm_freq(self) -> int:
        return self.finger_calib.get("pwm_freq", PWM_FREQ)

    def fingers(self) -> dict:
        """All finger servos keyed by int channel: finger_calib.json + EXTRA_FINGERS."""
        out = {ch: FingerServo(ch=ch, **cfg) for ch, cfg in EXTRA_FINGERS.items()}
        for ch, cfg in self.channels.items():
            out[int(ch)] = FingerServo(ch=int(ch), **cfg)
        return out

    # ratios.json
    @property
    def w_spring(self) -> dict:
        return self.ratios["w_spring"]

    def coupling_ratios(self) -> dict:
        """Follower / leader ratios from the measured curl fractions."""
        idx, thb = self.w_spring["5"], self.w_spring["1"]
        return {
            "index_pip": idx["pip"] / idx["mcp"],
            "index_dip": idx["dip"] / idx["mcp"],
            "thumb_ip":  thb["pip"] / thb["mcp"],
        }

    @property
    def thumb_add_deg_per_us(self) -> float:
        return self.w_spring["0"]["degrees per 100us"] / 100

    # scale_retarget.json
    @property
    def hand_scales(self) -> dict:
        """Robot / human finger length scale, e.g. {"index": 1.128, "thumb": 1.079}."""
        return {"index": self.scales["index"][0], "thumb": self.scales["thumb"][0]}

    @property
    def robot_lengths(self) -> dict:
        return {"index": self.scales["index"][1], "thumb": self.scales["thumb"][1]}


# =============================================================================
# ST bus servos
# =============================================================================

def _sdk():
    import scservo_sdk
    return scservo_sdk


class STBus:
    """One serial port shared by all ST bus servos."""

    def __init__(self):
        self.portHandler = None
        self.packetHandler = None

    @staticmethod
    def find_port(environment: Literal['mac', 'linux']) -> str:
        if environment == 'mac':
            ports = sorted(glob.glob('/dev/tty.usbmodem*') + glob.glob('/dev/tty.usbserial*'))
            if not ports:
                raise RuntimeError("No USB serial device found - is the servo board plugged in?")
            return ports[0]
        return ST_PORT_LINUX

    def open_port(self, port: str = ST_PORT_LINUX) -> bool:
        sdk = _sdk()
        self.portHandler = sdk.PortHandler(port)
        self.packetHandler = sdk.sms_sts(self.portHandler)
        return self.portHandler.openPort()

    def set_baud(self, baud: int = ST_BAUD) -> bool:
        return self.portHandler.setBaudRate(baud)

    def connect(self, port: str = ST_PORT_LINUX, baud: int = ST_BAUD) -> bool:
        """Open + set baud, printing the same messages the old scripts did."""
        if self.open_port(port):
            print("Succeeded to open the port")
        else:
            print("Failed to open the port")
            return False
        if self.set_baud(baud):
            print("Succeeded to change the baudrate")
        else:
            print("Failed to change the baudrate")
            return False
        return True

    def close(self):
        self.portHandler.closePort()

    def servo(self, name: str) -> "STServo":
        cfg = ST_SERVOS[name]
        return STServo(id=cfg["id"], pos=cfg["pos"], straight=cfg["straight"], flexed=cfg["flexed"],
                       portHandler=self.portHandler, min=cfg["min"], max=cfg["max"])

    def servo_by_id(self, servo_id: int) -> "STServo":
        for name, cfg in ST_SERVOS.items():
            min, max = cfg["min"], cfg["max"]
            if cfg["id"] == servo_id:
                return self.servo(name)
        return STServo(id=servo_id, pos=0, straight=0, flexed=0, portHandler=self.portHandler)

    def ping_scan(self, ids=range(1, 21)) -> list:
        """[(id, model, pos)] for every servo that answers."""
        sdk = _sdk()
        found = []
        for sid in ids:
            model, comm, err = self.packetHandler.ping(sid)
            if comm == sdk.COMM_SUCCESS:
                pos, comm2, err2 = self.packetHandler.ReadPos(sid)
                found.append((sid, model, pos))
        return found

    def broadcast(self, position: int, speed: int, acceleration: int):
        return self.packetHandler.WritePosEx(ST_BROADCAST_ID, position, speed, acceleration)


@dataclass
class STServo:
    id: int
    pos: int
    straight: int
    flexed: int
    portHandler: object
    min: Optional[int] = None
    max: Optional[int] = None
    ZERO_COUNTS = {
        1: 2000,
        2: 3000,
        3: 3052
        }

    def __post_init__(self):
        self.packetHandler = _sdk().sms_sts(self.portHandler)

    @staticmethod
    def counts_to_deg(counts: float) -> float:
        return counts / COUNTS_PER_DEG

    @staticmethod
    def deg_to_counts(deg: float) -> float:
        return deg * COUNTS_PER_DEG

    def write(self, position: int, speed: int, acceleration: int) -> bool:
        """Send the goal position. Returns False if the packet did not get through."""
        sdk = _sdk()
        scs_comm_result, scs_error = self.packetHandler.WritePosEx(self.id, position, speed, acceleration)
        if scs_comm_result != sdk.COMM_SUCCESS:
            print(f"{self.packetHandler.getTxRxResult(scs_comm_result)}")
            return False
        elif scs_error != 0:
            print(f"{self.packetHandler.getRxPacketError(scs_error)}")
        return True

    def move(self, position: int, speed: int, acceleration: int):
        """Write the goal position, then block until the servo stops."""
        self.write(position, speed, acceleration)
        self.wait()

    def wait(self):
        """Block until the servo stops, printing position and speed on every poll."""
        sdk = _sdk()
        while 1:
            # Read the current position of servo(ID)
            scs_present_position, scs_present_speed, scs_comm_result, scs_error = self.packetHandler.ReadPosSpeed(self.id)
            if scs_comm_result != sdk.COMM_SUCCESS:
                print(self.packetHandler.getTxRxResult(scs_comm_result))
            else:
                self.pos = scs_present_position
                print(f"[ID:{self.id:03d}] PresPos:{scs_present_position} PresSpd:{scs_present_speed}")
            if scs_error != 0:
                print(self.packetHandler.getRxPacketError(scs_error))

            # Read moving status of servo(ID)
            moving, scs_comm_result, scs_error = self.packetHandler.ReadMoving(self.id)
            if scs_comm_result != sdk.COMM_SUCCESS:
                print(self.packetHandler.getTxRxResult(scs_comm_result))

            if moving == 0:
                break
        return

    def wait_until_stopped(self, timeout: float = 6.0, poll: float = 0.02, settle: float = 0.15):
        """Quiet version of wait() with a deadline. Returns the last position read, or None."""
        import time
        sdk = _sdk()
        time.sleep(settle)
        deadline = time.time() + timeout
        reached = None
        while time.time() < deadline:
            pos, speed, comm, err = self.packetHandler.ReadPosSpeed(self.id)
            if comm != sdk.COMM_SUCCESS:
                print(self.packetHandler.getTxRxResult(comm))
            elif err != 0:
                print(self.packetHandler.getRxPacketError(err))
            else:
                reached = pos

            moving, comm, err = self.packetHandler.ReadMoving(self.id)
            if comm != sdk.COMM_SUCCESS:
                print(self.packetHandler.getTxRxResult(comm))
            elif moving == 0:
                return reached

            time.sleep(poll)

        print(f"timeout waiting for servo {self.id}")
        return reached
    @staticmethod
    def sim_to_real(id:int, angle_rad:float, dir:int):
            if np.isnan(angle_rad):
                raise ValueError(f"invalid angle value")
            if dir not in (-1, 1):
                raise ValueError(f"Direction needs to be either 1 or -1.")
            if id not in STServo.ZERO_COUNTS:
                raise ValueError(f"no zero calibration for servo {id}")
            else:
                counts = STServo.ZERO_COUNTS[id] + dir * GEAR_RATIO[id] * np.degrees(angle_rad) * COUNTS_PER_DEG
                if not 0 <= counts <= 4095:
                    raise ValueError(f"Katarzyna, these counts are unacceptable! Your robot can't do these!")
                for ix, val in ST_SERVOS.items():
                    if val["id"] == id:
                        lo, hi = val["min"], val["max"]
                        if lo is None and hi is None:
                            continue
                        else: 
                            print('Joint has a set range limit')
                        return int(round(np.clip(counts, lo, hi)))
            return int(round(counts))


# =============================================================================
# PCA9685 finger servos
# =============================================================================

@dataclass
class FingerServo:
    ch: int
    name: str
    position: Optional[int] = None   # grasp target, us
    release: Optional[int] = None    # release target, us
    straight: Optional[int] = None   # us at straight
    flexed: Optional[int] = None     # us at full flex

    @property
    def limits(self) -> tuple:
        """(lo, hi) travel limits in us, ordered low-to-high."""
        return min(self.straight, self.flexed), max(self.straight, self.flexed)

    def frac_to_us(self, frac: float) -> float:
        """0.0 = straight .. 1.0 = flexed."""
        return self.straight + frac * (self.flexed - self.straight)


class FingerBoard:
    """PCA9685 board driving the finger servos.

    backend="circuitpython" -> adafruit_pca9685 over board/busio, duty_cycle in 16 bit
    backend="legacy"        -> Adafruit_PCA9685 on busnum=1, set_pwm in 12 bit counts
    """

    def __init__(self, calib: Optional[Calibration] = None, freq: int = PWM_FREQ,
                 backend: Literal["circuitpython", "legacy"] = "circuitpython"):
        self.calib = calib if calib is not None else Calibration.load()
        self.freq = freq
        self.backend = backend
        self.servos = self.calib.fingers()
        self.by_name = {s.name: s for s in self.servos.values()}
        self.pca = None
        self.pwm = None

    def connect(self):
        if self.backend == "circuitpython":
            from board import SCL, SDA
            import busio
            from adafruit_pca9685 import PCA9685
            i2c = busio.I2C(SCL, SDA)
            self.pca = PCA9685(i2c)
            self.pca.frequency = self.freq
        else:
            from Adafruit_PCA9685 import PCA9685
            self.pwm = PCA9685(busnum=1)
            self.pwm.set_pwm_freq(self.freq)
        return self

    # circuitpython path
    def us_to_duty(self, us):
        period_us = 1_000_000 / self.freq
        return int(us / period_us * 65535)

    def move_us(self, ch, us, verbose=True):
        if verbose:
            print(f"ch {ch}: {us} us")
        self.pca.channels[ch].duty_cycle = self.us_to_duty(us)

    def release_channel(self, ch):
        self.pca.channels[ch].duty_cycle = 0

    # legacy path
    def move_to_angle(self, name, position, angle_min, angle_max):
        """Map a hand angle in [angle_min, angle_max] onto the servo's straight..flexed range."""
        s = self.by_name[name]
        frac = float(np.clip((position - angle_min) / (angle_max - angle_min), 0.0, 1.0))
        us = s.frac_to_us(frac)
        counts = int(np.clip(us / LEGACY_US_PER_COUNT, LEGACY_COUNT_MIN, LEGACY_COUNT_MAX))
        self.pwm.set_pwm(s.ch, 0, counts)

    def pwm_off(self, name):
        self.pwm.set_pwm(self.by_name[name].ch, 0, 0)

    # calibrated grasp targets (circuitpython path)
    def finger_limits(self, ch):
        return self.servos[int(ch)].limits

    def validate(self, channels=None) -> bool:
        ok = True
        for ch in channels if channels is not None else sorted(self.calib.channels, key=int):
            s = self.servos[int(ch)]
            lo, hi = s.limits
            for key in ("position", "release"):
                val = getattr(s, key)
                if not lo <= val <= hi:
                    print(f"  ! {s.name}: {key}={val} is outside travel {lo}-{hi}")
                    ok = False
        if ok:
            print("  calibration OK")
        return ok

    def move_finger(self, ch, target_us):
        lo, hi = self.finger_limits(ch)
        pos = int(round(max(lo, min(hi, target_us))))
        if abs(pos - target_us) > 1:
            print(f"  clamped {self.servos[int(ch)].name}: {target_us:.0f} -> {pos}")
        self.move_us(int(ch), pos)

    def set_fingers(self, key, wrist_now=None, channels=None):
        """key is 'position' (grasp) or 'release'. Applies tenodesis if wrist_now given."""
        for ch in channels if channels is not None else sorted(self.calib.channels, key=int):
            target = getattr(self.servos[int(ch)], key)
            if wrist_now is not None:
                target += self.calib.tenodesis_k * (wrist_now - self.calib.wrist_tilt_ref)
            self.move_finger(ch, target)

    def sim_to_real(self, ch, angle):
        angle_flexed, angle_straight = EXTRA_FINGERS[ch]["flexed"], EXTRA_FINGERS[ch]["straight"]
        angle = (angle - angle_straight)/(angle_flexed - angle_straight)
        us = FingerBoard.frac_to_us(np.clip(angle, 0, 1))
        return us

# =============================================================================
# Real robot
# =============================================================================

class RobotArm:
    """ST bus servos + PCA9685 fingers. Nothing opens until connect()."""

    def __init__(self, environment: Literal['mac', 'linux'] = 'linux', calib: Optional[Calibration] = None,
                 finger_backend: Literal["circuitpython", "legacy"] = "circuitpython"):
        self.environment = environment
        self.calib = calib if calib is not None else Calibration.load()
        self.bus = STBus()
        self.fingers = FingerBoard(self.calib, freq=self.calib.pwm_freq, backend=finger_backend)
        self.wrist_rotator = None
        self.wrist_tilter = None
        self.elbow = None

    def connect(self, st: bool = True, fingers: bool = True):
        if st:
            port = STBus.find_port(self.environment)
            if not self.bus.connect(port, self.calib.st_baud):
                raise RuntimeError(f"Failed to open {port} at {self.calib.st_baud} baud")
            self.wrist_rotator = self.bus.servo("wrist rotate")
            self.wrist_tilter = self.bus.servo("wrist tilt")
            self.elbow = self.bus.servo("elbow")
        if fingers:
            self.fingers.connect()
        return self

    def st(self, servo_id: int) -> STServo:
        return {s.id: s for s in (self.wrist_rotator, self.wrist_tilter, self.elbow)}[servo_id]

    def wrist_to(self, pos):
        self.st(self.calib.wrist_id).move(int(pos), self.calib.wrist_speed, self.calib.wrist_accel)
        return int(pos)

    def close(self):
        self.bus.close()


# =============================================================================
# Hand pose (human keypoints -> angles)
# =============================================================================
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

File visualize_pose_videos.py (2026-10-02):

from pathlib import Path
import torch
import argparse
import os
import cv2
import numpy as np
import json
from typing import Dict, Optional
import sys, os
sys.path.insert(0, os.path.join(os.path.dirname(__file__), "WiLoR"))


from wilor.models import WiLoR, load_wilor
from wilor.utils import recursive_to
from wilor.datasets.vitdet_dataset import ViTDetDataset, DEFAULT_MEAN, DEFAULT_STD
from wilor.utils.renderer import cam_crop_to_full
from ultralytics import YOLO 



def main():
    parser = argparse.ArgumentParser(description='WiLoR demo for robot arm - no rendering, video input')
    parser.add_argument('--video', type=str, default='/Users/katarzynadlugosz/Downloads/sewing_recording.mp4', help='Path to input video')
    parser.add_argument('--out_folder', type=str, default='video_out', help='Output folder to save pose data')
    parser.add_argument('--save_mesh', dest='save_mesh', action='store_true', default=False, help='If set, save meshes to disk')
    parser.add_argument('--rescale_factor', type=float, default=2.0, help='Factor for padding the bbox')
    parser.add_argument('--file_type', nargs='+', default=['*.jpg', '*.png', '*.jpeg'], help='List of file extensions to consider')
    parser.add_argument('--fast',   dest='fast', action='store_true', default=False, help='Use FP16 and layer dropping to accelerate inference')
    args = parser.parse_args()

    # model load - start of wilor copy
    print("Loading WiLoR model...")
    model, model_cfg = load_wilor(checkpoint_path='./pretrained_models/wilor_final.ckpt', cfg_path='./pretrained_models/model_config.yaml')
    if args.fast:     
        torch.set_float32_matmul_precision('high')
        model = model.half()
        model.backbone = torch.compile(model.backbone)
        model.backbone.skip_blocks = True 
        
    print("Loading hand detector...")
    detector = YOLO('./pretrained_models/detector.pt')
    
    device   = torch.device('cuda') if torch.cuda.is_available() else torch.device('cpu')
    model    = model.to(device)
    detector = detector.to(device)
    model.eval()
    # end of copy

    # Make output directory if it does not exist
    os.makedirs(args.out_folder, exist_ok=True)

    # getting the video properties
    cap = cv2.VideoCapture(args.video)
    fps    = cap.get(cv2.CAP_PROP_FPS)
    width  = int(cap.get(cv2.CAP_PROP_FRAME_WIDTH))
    height = int(cap.get(cv2.CAP_PROP_FRAME_HEIGHT))
    total  = int(cap.get(cv2.CAP_PROP_FRAME_COUNT))

    print(f"Found {total} frames")
    # start of inference
    for frame_idx in range(total):
        ret, img_cv2 = cap.read()
        if not ret:
            print(f"  Error: Could not read frame {frame_idx}")
            continue

        # Detect hands
        print(f"  Detecting hands...")
        detections = detector(img_cv2, conf=0.3, verbose=False)[0]
        
        bboxes = []
        is_right = []
        conf = []
        for det in detections:
            Bbox = det.boxes.data.cpu().detach().squeeze().numpy()
            is_right.append(det.boxes.cls.cpu().detach().squeeze().item())
            bboxes.append(Bbox[:4].tolist())
            conf.append(float(Bbox[4]))
        
        if len(bboxes) == 0:
            print(f"  No hands detected")
            continue
        
        print(f"  Found {len(bboxes)} hand(s)")
        
        frame_name = f"frame{frame_idx:06d}"
        frame_path = os.path.join(args.out_folder, f"{frame_name}.png")
        cv2.imwrite(frame_path, img_cv2)
        boxes = np.stack(bboxes)
        right = np.stack(is_right)
        
        # Prepare dataset
        dataset = ViTDetDataset(model_cfg, img_cv2, boxes, right, rescale_factor=args.rescale_factor, fp16=args.fast)
        dataloader = torch.utils.data.DataLoader(dataset, batch_size=16, shuffle=False, num_workers=0) 

        # Process each batch
        print(f"  Estimating hand pose...")
        for batch in dataloader: 
            batch = recursive_to(batch, device)
    
            with torch.no_grad():
                out = model(batch) 
                
            multiplier    = (2*batch['right']-1)
            pred_cam      = out['pred_cam']
            pred_cam[:,1] = multiplier*pred_cam[:,1]
            box_center    = batch["box_center"].float()
            box_size      = batch["box_size"].float()
            img_size      = batch["img_size"].float()
            scaled_focal_length = model_cfg.EXTRA.FOCAL_LENGTH / model_cfg.MODEL.IMAGE_SIZE * img_size.max()
            pred_cam_t_full = cam_crop_to_full(pred_cam, box_center, box_size, img_size, scaled_focal_length).detach().cpu().numpy()

            # Extract and save hand pose data
            batch_size = batch['img'].shape[0]
            for n in range(batch_size):
                frame_name, _ = f"frame{frame_idx:06d}", None  # Use frame index as filename
                joints = out['pred_keypoints_3d'][n].detach().cpu().numpy()  # 21 hand joints
                is_right_hand = batch['right'][n].cpu().numpy()
                # Mirror x-axis if right hand
                joints[:,0] = (2*is_right_hand-1)*joints[:,0]
                
                cam_t = pred_cam_t_full[n]  # Camera translation [tx, ty, tz]
                
                # Save as JSON for easy loading in robot code
                pose_data = {
                    'image': frame_path,
                    'hand_index': n,
                    'is_right_hand': bool(is_right_hand),
                    'confidence': float(conf[n]) if len(conf) > n else None,
                    'camera_translation': cam_t.tolist(),  # [tx, ty, tz]
                    'focal_length': float(scaled_focal_length.cpu().numpy()),
                    'hand_joints': joints.tolist(),   # 21x3 - hand keypoints
                }
                #end of wilor copy
                pose_file = os.path.join(args.out_folder, f'{frame_name}_hand{n}.json')
                with open(pose_file, 'w') as f:
                    json.dump(pose_data, f, indent=2)
                print(f"    Saved pose to {os.path.basename(pose_file)}")
                

    print("\nDone!")
    cap.release()

if __name__ == '__main__':
    main()

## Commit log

2026-07-17 Add video pose analysis script
    - visualize_pose_videos.py: run WiLoR hand-pose estimation frame-by-frame
    over a video, saving per-hand JSON per frame
    - .gitignore: exclude generated pose output folders
2026-07-17 Save detection confidence and slim output to joints
    - capture YOLO per-hand detection confidence and store it in each JSON
    - add sys.path shim so wilor imports resolve when run from repo root
    - drop hand_vertices/mesh output; keep 21 joints per hand
    [visualize_pose_videos.py]
2026-07-19 Add project notes, remove unused WiLoR_base stub
    - notes.md: pipeline overview and hand-joint index reference
    - delete WiLoR_base.py (placeholder no longer used)
2026-07-21 Add joint aggregator and left-hand orientation fix
    - glob_json.py: aggregate per-frame right-hand joints/confidence from
    video_out into a single .npz (keeps highest-confidence right hand)
    - visualize_pose.py: mirror left-hand joints so 3D view isn't flipped
    - visualize_pose_videos.py: minor cleanup
    [glob_json.py, visualize_pose.py, visualize_pose_videos.py]
2026-07-21 Add npz scan/plot script (WIP) and WiLoR_base stub
    - npz_scan_plot.py: load aggregated npz and plot fingertip trajectory
    (work in progress)
    - WiLoR_base.py: base module stub
2026-07-21 Add finger-angle retargeting; notes and aggregator tweaks
    - retarget_to_servo.py: compute per-finger curl angles from npz joints
    (two-segment sum per finger; NaN for frames with no hand)
    - glob_json.py: prep camera_translation array (not yet populated)
    - notes.md: update project notes
2026-07-21 Add servo translation (WIP); rename retarget module to angle_computation
    - servo_translate.py: map finger angles to PCA9685 servo pulses (Pi-side,
    work in progress — not yet runnable)
    - rename retarget_to_servo.py -> angle_computation.py
    - README update
2026-07-30 ST servo scripts, wrist testing, coupling work
2026-07-30 Finger calibration and coupling test
2026-08-05 Testing finger grasp with silicon pads, calibrating grasp, camera setup for Jetson Orin Nano
2026-08-06 Camera capture on Jetson, USB webcam working
2026-08-07 Inverse kinematics for arm operation, grasp tests.
2026-08-12 Forward kinematics sketch
2026-09-08 Finger calib against physical footage with respect to joint limits
    [position_log.csv]
2026-09-11 Validating fk againts ik, measured bone ratios
    [position_log.csv, vid_log.csv]
2026-09-14 Fix for passive links
    [limits.py, map_angle.py, position_log.py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]
2026-09-15 Sinusoid path for mujoco demo, driverless update for f_kinematics.
2026-09-15 Add MuJoCo model and meshes
    [2076278-v1.stl, Craft_Needle.STL, arm1-1.stl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]
2026-09-16 Wrist tilt/roll from palm frame
2026-09-26 Vector retargeting: hand-size scales, tip-position optimiser, coupling ratio fix
    [glob_json.py, servo_translate_new.py, visualize_pose_videos.py]
2026-10-02 Add arm.py module, grip/retargeting sims; move estimators to cam/, retire old scripts
2026-10-08 Add MuJoCo model + meshes, sim/retarget videos, sample WiLoR data
    [finger_pad.stl]
2026-10-08 Add hardware, CAD and capture images
2026-10-08 Update arm and grip sim
2026-10-08 Update README to clarify data collection details
    Removed reference to sample clip and simplified data collection description.
2026-10-08 README rewrite, fix image names, add sample data
2026-10-08 README rewrite, image fixes, sample data, remove stale elbow TODO
    [arm.py]
2026-10-14 Add training ground + policy notebook
2026-10-22 Camera translation using cm in the frame, global updates to focal lenght
2026-10-28 Sim-to-real replay and fine-tuning of the fingertip distances in retargeting.
2026-10-28 clip03 with middle finger
2026-10-29 EMA filter on arm motion and grasp calculation refinement
2026-11-10 Updated forces, pierce tracker for the needle, penalty for collision with the frame
2026-11-10 Adding additional frame chunks for learning
2026-11-11 Roll fix, fabric/frame contacts, ring+pinky replay, env fabric force
